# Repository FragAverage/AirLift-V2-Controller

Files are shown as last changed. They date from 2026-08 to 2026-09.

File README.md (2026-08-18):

# AirLift V2 Controller

The **AirLift V2 Controller** is a man-in-the-middle controller that sits inline
between an **AirLift V2 Controller controller** and the **air-management
manifold**. It **decodes the proprietary 9600-baud LIN-wired protocol**
in both directions, **rewrites frames if required** so a phone or the vehicle can
drive presets and manual air-up/down without ever desyncing the OEM Controller,
and **reads the vehicle CAN bus** for ignition sensing, lock/unlock triggers (like key fob)
and a live pressure broadcast. Everything is configured from a phone over
**Wi-Fi** — no laptop or serial cable needed in the car.

It runs on the same **ESP32 DevKit V1 (WROOM-32)** PCB as the
[MFSW Controller](https://forbes-automotive.com/products/lin-mfsw-controller),
under the Arduino framework, using both hardware UARTs for the two LIN sides and
the ESP32 **TWAI** peripheral for CAN.

> The firmware acts as a relay and only intercepts
> the manifold bus transiently while a command is queued — control always
> returns to the controller automatically.

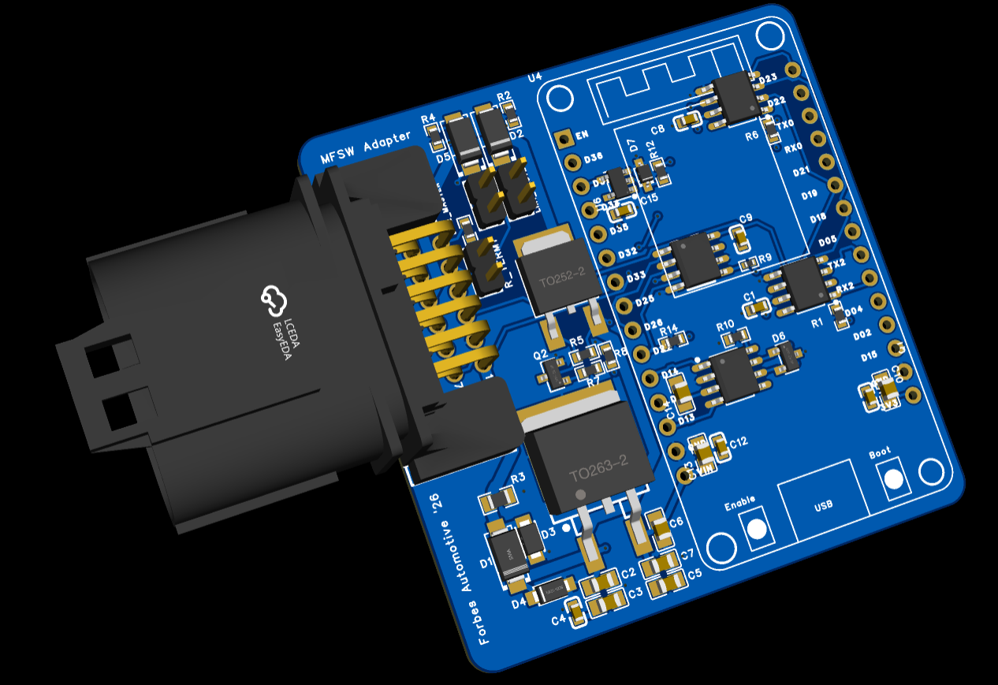
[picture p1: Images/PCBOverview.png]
PCB Overview


---

## Features at a Glance

| Feature | Detail |
|---|---|
| Dual-LIN | Dual LIN channels for Controller (UART1) and manifold (UART2) in dedicated FreeRTOS tasks |
| AirLift Decoder | Decodes every observed frame: FA/F3 polls & replies, the 17-byte status frame, and the 14-byte format-B pressure broadcast |
| Rewrite-in-flight injection | Presets, manual buttons, mode-switch — with verified checksums; the manifold only ever sees one continuous master, so it can't desync |
| Preset editor | Each of 8 presets stored as a `(frontPsi, rearPsi)` in EEPROM, plus a live **Learn** capture from the Controller to allow the user to learn each preset |
| Auto air-out | On ignition loss, broadcast the configured "air-down" target (preset or manual), hold, then turn off manifold power |
| CAN / TWAI | Powertrain quiet-bus ignition detection **or** Comfort-CAN lock/unlock triggers, plus a ~10 Hz pressure broadcast onto the selected bus |
| SavvyCAN GVRET | Capture/inject CAN over Wi-Fi (TCP 23) or USB serial for reverse-engineering |
| Lock/unlock air actions | A double fob-unlock airs the car up; a double fob-lock airs it down (both individually selectable) |
| High-side driver | Powers the controller whenever the vehicle is awake, with configurable CAN silence / min-FPS thresholds |
| Slave display | ~10 Hz ESP-NOW broadcast of pressures / preset / air state to a cluster-mounted CYD display (`SlaveDisplay/`) |
| Wi-Fi UI | Overview, Presets, Settings, Diagnostics, OTA |
| Power management | Auto Wi-Fi-off + CPU reduction 1 minute after the last client disconnects; a fresh CAN burst wakes it back up |
| OTA updates | Flash new firmware from the browser over Wi-Fi |
| EEPROM storage | All settings and presets stored to ESP32 Preferences |

---

### Purchase

The controller runs on the same PCB as the LIN MFSW Controller, available here:
[LIN MFSW Controller — Forbes Automotive](https://forbes-automotive.com/products/lin-mfsw-controller)

---

## Compatibility

Designed for the **AirLift V2** controller + manifold pair that communicate over a
**9600-baud 8N1 LIN-transceiver bus**. The controller is the **bus master** (the
bus is silent when it is unplugged). Frame formats, button codes and checksums
in [`include/defs.h`](include/defs.h) were reverse-engineered from live Saleae
captures (see [`Documents/`](Documents/)) — treat them as a known-good baseline
and re-verify against your own hardware before relying on any injected output.

CAN frame IDs (Comfort fob, broadcast) are **VW PQ-specific** and configurable.

---

## Hardware Overview

### External Interfaces

| Function | Part / circuit |
| --- | --- |
| Controller LIN (LIN 1) | LIN transceiver on `Serial1`, 9600 8N1 — the controller is the master, this device relays it |
| Manifold LIN (LIN 2) | LIN transceiver on `Serial2`, 9600 8N1 — the manifold is the slave |
| CAN | ESP32 TWAI + transceiver (TJA1050 / SN65HVD230); 500 kbit/s Powertrain or 100 kbit/s Comfort |
| Ignition sense (aux) | Optional 12 V level input on the shared aux pin (GPIO 39, input-only) for instant ignition |
| High-side driver | Transistor output (OUTPUT1) supplies +12 V to the controller during ignition-off air-out (5A max.) |

### Pin Map

Defined in [`include/defs.h`](include/defs.h):

| Group | Signal | GPIO |
| --- | --- | --- |
| LIN 1 (Controller) | TX / RX | 17 / 16 |
| LIN 2 (manifold) | TX / RX | 23 / 22 |
| LIN transceivers | Wake / CS-EN | 18 / 19 |
| CAN / TWAI | RX / TX | 13 / 14 |
| Ignition sense | Aux input (input-only pin) | 39 |
| High-side driver | Controller +12 V ("PNP") | 21 |

UARTs are 9600 8N1; CAN is 500 kbit/s (Powertrain) or 100 kbit/s (Comfort).

### Main Connector

The device breaks out to a single 12-way **MX23A12NF1** connector (shared PCB
with the MFSW controller):

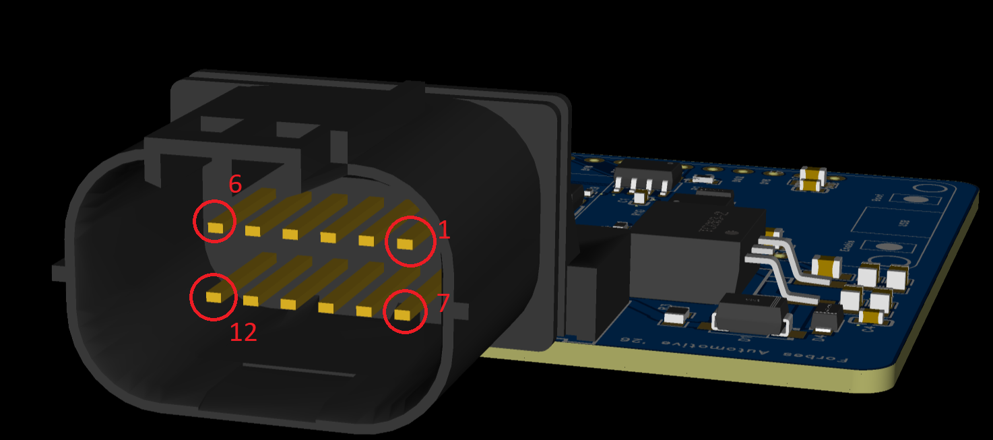
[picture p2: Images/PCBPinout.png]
Main Connector Pinout


> Viewed into the mating face: the top row runs pin **1** (right) to pin **6**
> (left), and the bottom row runs pin **7** (right) to pin **12** (left).

| Pin | Signal | AirLift use |
| --- | --- | --- |
| 1 | `PWR_IN` | 12 V switched / ignition supply |
| 2 | `GND` | Ground |
| 3 | `LIN1` | Controller LIN bus |
| 4 | `LIN2` | Manifold LIN bus |
| 5 | `CHASSIS_CANH` | CAN high |
| 6 | `CHASSIS_CANL` | CAN low |
| 7 | `ANALOG_LIGHT_IN` | Optional ignition-sense input (aux) |
| 8 | `RA` | Unused (resistive output not populated) |
| 9 | `5V` | 5 V rail — typically not required |
| 10 | `OUTPUT1` | Controller +12 V high-side driver |
| 11 | — | Unused |
| 12 | — | Unused |

---

## Jumpers

The shared PCB carries three configuration jumpers:

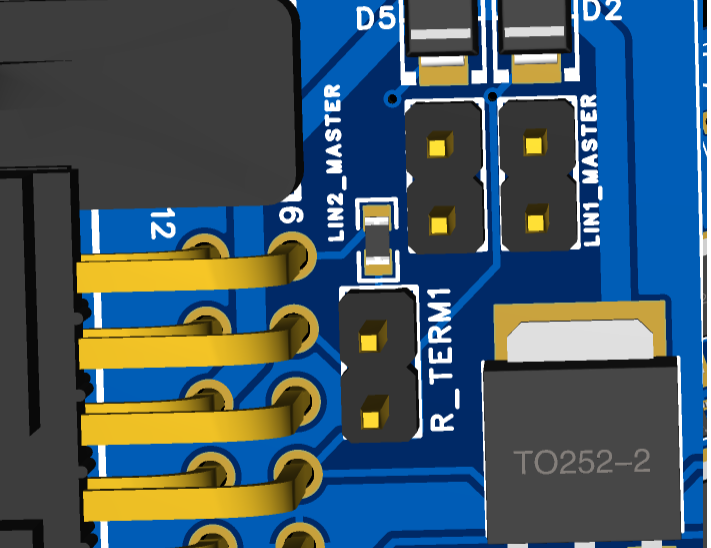
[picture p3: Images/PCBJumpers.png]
Board Jumpers


### LIN1_MASTER

Master pull-up on **LIN 1** (the controller bus). The AirLift Controller provides
the bus master, so this jumper is normally **left off** on the adapter — fit it
only if bench-testing without the real Controller attached.

### LIN2_MASTER

Master pull-up on **LIN 2** (the manifold bus). Fit it if the adapter must
provide the master pull-up on the manifold side; remove it if the manifold
harness already supplies one.

### R_TERM1

The **CAN bus termination resistor**. If this is the only device on the CAN
network leave it fitted; if the vehicle bus is already terminated, remove it.

---

## How It Works

The two LIN sides and the CAN bus each run in dedicated FreeRTOS tasks. The
firmware never seizes the manifold bus outright — the real Controller keeps
polling at its own rate and the firmware simply **rewrites those
frames as they pass through**. Because the manifold only ever sees one
continuous, correctly framed master it can never desync.

```
Controller LIN (master)                Manifold LIN (slave)              Vehicle CAN
        │                                   ▲                              │
        ▼ ControllerToManifoldTask (core 1)   │ manifoldToControllerTask       ▼ ignitionTask (core 0)
 parse poll / button ────────────┐          │ (core 1)                pollCanRx()
        │                        │          │  parse status/pressure       │
   RESTING: byte relay ──────────┼──────────┘  RESTING: byte relay         ▼ switch(id):
        │                        │          ▲       │                 Comfort 0x291 → lock/unlock
   COMMAND: drop poll,           │          │       ▼                       │
   drive manifold ~20 Hz ────────┘   rewrite reply, credit-gated       air-up / air-down queue
        (transformControllerFrame)      relay back to Controller                │
                                                                            ▼ canBroadcastTick()
                                                                     8-byte pressure frame (~10 Hz)
```

### Resting vs. Command

- **Resting** (the default) is a real-time byte-for-byte relay in both
  directions. Both channels still parse a side-channel copy of the traffic, so
  pressures, mode and button state stay live without slowing the bus.
- **Command** (a queued web/CAN action) drops the Controller's messages and drives the manifold at the OEM's active ~20 Hz rate. 

### Air-up / Air-down Triggers

| Source | Action |
| --- | --- |
| Web UI preset / manual buttons | Queue a preset target or manual corner move |
| Ignition loss (`airOutOnIgnOff`) | Broadcast the configured air-down target, hold, drop Controller power |
| Comfort-CAN **double unlock** (`airUpOnFobDouble`) | Air up to the configured preset / PSI |
| Comfort-CAN **double lock** (`airDownOnFobDouble`) | Air down to the configured preset / PSI |

Manual-target moves are closed-loop: the firmware pulses the matching corner
button until the measured axle PSI reaches the target (within tolerance) or the
60s timeout expires.  This may need adjustment(!).

---

## LIN Protocol (Reverse-Engineered)

### Format A — FA-framed polls and replies

```
FA  <payload bytes>  F3
```

**Controller → Manifold (master polls)**

| Bytes | Meaning |
|---|---|
| `01 00 05` | idle poll |
| `01 41 XX YY` | MANUAL-mode button event, `YY = (0xC4 - XX) & 0xFF` |
| `01 14 40 00 00 00 B1` | PRESET-mode entry poll (state `0x40`, one-shot) |
| `01 14 43 00 00 00 AE` | PRESET-mode steady poll (state `0x43`) |
| `01 16 47 TL TR 0F TL TR CHK` | preset target broadcast; `TL`/`TR` = front/rear PSI × 2 |

**Manifold → Controller (slave replies)**

| Bytes | Meaning |
|---|---|
| `10 F1 00 05` | idle reply |
| `10 F1 04 01` | reply, MANUAL mode |
| `10 F1 01 04` | reply, PRESET mode |
| `10 0E 00 25 …` | 17-byte status frame (see below) |

### Manual Button Codes (`01 41 XX YY`, payload[2])

Upper nibble = axle (5 = front, 6 = rear); lower nibble = one-hot bit per
(side, direction): bit0 = L-UP, bit1 = L-DOWN, bit2 = R-UP, bit3 = R-DOWN.

| Code | Button |  | Code | Button |
|---|---|--|---|---|
| 0x51 | FL_UP |  | 0x61 | RL_UP |
| 0x52 | FL_DOWN |  | 0x62 | RL_DOWN |
| 0x54 | FR_UP |  | 0x64 | RR_UP |
| 0x58 | FR_DOWN |  | 0x68 | RR_DOWN |
| 0x00 | release/idle |  | 0x80 | MODE_SWITCH (press+hold 1+5) |

Checksum: payload[3] = `(0xC4 - code) & 0xFF`.

### Format A — 17-byte status frame (Manifold → Controller)

```
FA 10 0E 00 MS  FL  RL  FR  RR  TANK  C8 00 00 00 33 00 CHK F3
```

- `payload[3]` = mode/compressor flags: bit5 (`0x20`) heartbeat, bit4 (`0x10`)
  poll-parity, bits0+2 (`0x05`) both set if the compressor is running.
- `payload[5..8]` = FL, RL, FR, RR raw PSI (× 1, **not** × 2).
- `payload[9]`    = tank raw PSI.
- `payload[16]`   = sum-checksum: `(0xFA + Σpayload[0..15] + chk) mod 256 == 0`.

### Format B — 14-byte pressure broadcast (idle-terminated, no FA/F3)

```
00 0A E6 7E   C8 00 4A 00   FL  FR  RL  RR  b12 b13
```

Pressure bytes are PSI × 2. Frame is terminated by ≥4 ms of bus silence
(`kFrameIdleMs`). Kept as a secondary pressure source; format-A status is
preferred when available.

> **Pressure Refresh Rate.** In resting mode pressures are parsed on
> *every* frame the manifold emits, so the on-device values are always as fresh
> as the bus allows. The dashboard now polls `/api/status` at 4 Hz (250 ms).
> The underlying rate is set by how often the manifold chooses
> to broadcast

---

## CAN / TWAI

- **Listen-only** by default; reset to NORMAL mode only when *CAN Broadcast* or
  SavvyCAN transmit is enabled, so the firmware never emits ACK/error bits onto
  a bus while just monitoring.
- Re-initialised in [`src/CAN.cpp`](src/CAN.cpp) (`canReinit()`) when the
  enable flag, ID or bus rate changes via `/api/settings`.

### CAN Source

Exactly one CAN bus is active at a time (a single TWAI controller can only run
at one bit-rate):

- **Powertrain CAN** (500 kbit/s, default) — quiet-bus / minimum-FPS ignition
  detection. Presence is decided by combined activity: silence longer than
  `canSilSec` (default 10 s) **and** frame rate below `canMinFps` (default 50) →
  ignition OFF.
- **Comfort CAN** (100 kbit/s) — parses lock/unlock. `pollCanRx()` feeds each
  frame to a simple `switch (frame.identifier)` case statement; the Comfort fob
  frame (`0x291`, byte 0 = `0x4B` unlock / `0x8B` lock) sets the lock state, and
  a **double** press within 5s queues the configured air-up (unlock) or
  air-down (lock) action.

### Lock/Unlock → Air-Up/Down 

```
Comfort frame 0x291 → canProcessFrame() switch → unlock/lock + double-press detect
                                              → comfortFobDoubleUnlock / …Lock flag
ignitionTask → sees flag → queueTarget(air-up | air-down) → manifold drive
```

### Pressure Broadcast (firmware → vehicle bus)

~10 Hz (`kCanBroadcastPeriodMs = 100`), user-configured 11-bit ID (default
`0x520`), DLC 8:

```
[0] FL PSI*2   [1] FR PSI*2   [2] RL PSI*2   [3] RR PSI*2   [4] Tank PSI*2
[5] flags: bit0 compOn | bit1 ignOn | bit2 intercept | bit3 passthru
          | bits4-5 mode (0=unknown,1=manual,2=preset)
[6] seq counter (free-running)   [7] reserved (0)
```

### Slave Display Broadcast (firmware → ESP-NOW)

A one-way ~10 Hz (`kEspNowPeriodMs = 100`) broadcast to `FF:FF:FF:FF:FF:FF` of
the 24-byte `AirLiftData` struct in `include/airlift_espnow.h` — the receiving
end is the cluster display in **`SlaveDisplay/`**. Broadcast means no pairing and
no knowledge of the display's MAC; nothing is ever received.

```
float fl, fr, rl, rr, tank   // PSI
uint8 preset                 // 1-8 active preset, 0 = none
uint8 status                 // 0 idle, 1 raising, 2 lowering, 3 no signal
```

The struct must stay **byte-identical** to `SlaveDisplay/include/airlift_espnow.h`
(a `static_assert` on both sides guards the size; the receiver can only check the
length, not the field layout).

Two things the LIN wire does not carry directly, so the firmware derives them:

- **Active preset** — the wire has no preset index, only the target pressures
  from `01 16 47`. Those are matched back against the configured/learned preset
  table, which is the same mapping the UI's preset list uses. No match, or not in
  PRESET mode, sends `0` and the display shows `---`.
- **Raising / lowering** — the compressor bit only says the pump is running
  (also true while it refills the tank). Direction comes from a button being held
  right now (ours or the handheld's), and otherwise from the trend of the corner
  pressures, which also covers preset moves where the manifold closed-loops with
  no button held at all.

Because ESP-NOW rides the Wi-Fi radio, the soft-AP channel is pinned to
`kEspNowChannel` (1) to match the display's fixed `ESPNOW_WIFI_CHANNEL`, and the
radio is held up while the broadcast is enabled **and** the ignition is on — see
Power Management below. Toggle in **Settings → Slave Display (ESP-NOW)**.

### SavvyCAN

Enable one setting in **Settings → SavvyCAN**:

- **Wi-Fi GVRET**: connect SavvyCAN to `192.168.1.1:23` as a GVRET network device.
- **Serial GVRET**: connect SavvyCAN to the USB serial port at `1,000,000` baud.

All received frames are forwarded through a queue; SavvyCAN transmit
requests are sent to the vehicle bus while either transport is active.

---

## Power Management

The firmware bundles the universal `power_manager` module used across the
projects. Power state follows the **Wi-Fi client count**, and CAN traffic is the
**wake source** — matching the "sleep when idle, wake when you return to the car"
behaviour:

1. **Boot** — Wi-Fi AP is up and full power.
2. **Idle** — **1 minute after the last Wi-Fi client disconnects**, the module
   turns the WiFi off, drops the CPU 240 MHz → 80 MHz, and clears any web
   override so the controller rests as a pure pass-through. This happens even while the
   car is running (CAN active), keeping the linear regulator cool.
3. **Wake** — while reduced, the TWAI controller keeps receiving (we never
   light-sleep, so no wake interrupt is needed — `ignitionTask` drains the RX
   FIFO every 100 ms). When the bus goes from **quiet → active** and a genuine
   **burst of ≥ `kCanWakeFrameMin` (8) frames** arrives, the board wakes and
   rebuilds the AP for the idle window. It sleeps again 1 minute later if no
   client connected.

> With the ESP-NOW slave display enabled, the radio is **held up while the
> ignition is on** — a cluster gauge that goes blank a minute into a drive is
> worse than the regulator heat it saves. Ignition off (car parked, display
> unpowered) reduces exactly as described above. Turn the broadcast off in
> Settings to restore the old behaviour in full.

> Lock/unlock parsing and air-up/down run in `ignitionTask` and are **independent
> of Wi-Fi** — a fob double-unlock airs the car up whether or not the WiFi is
> awake. The wake-on-burst only restores the web UI.

| Action | Saving |
| --- | --- |
| Wi-Fi off | ~80–120 mA average (single biggest) |
| CPU 240 MHz → 80 MHz | Moderate reduction in active current |
| Bluetooth controller released at boot | ~60 KB RAM freed; small idle saving |
| Onboard LED off at boot | Tiny but persistent saving |

A single stray CAN frame will **not** wake the AP, and a continuous stream that
started while awake will **not** re-wake it after it sleeps — only a fresh
quiet-to-active burst does. An ignition power-cycle always brings Wi-Fi back.

---

## Wi-Fi & Web Interface

Connect to the **`AirLift-V2 Controller`** Wi-Fi access point and browse to
**`http://192.168.1.1/`**. All changed settings are saved automatically.

| Tab | Purpose |
| --- | --- |
| **Overview** | Live FL/FR/RL/RR/Tank PSI, compressor LED, mode, press-and-hold corner buttons (Pointer Events with a safety release), and bus health |
| **Presets** | 8 named buttons + inline `(frontPsi, rearPsi)` editor |
| **Settings** | Pass-through, intercept, air-out-on-ignition-off, air-up/down on fob double-press, CAN source + silence/min-FPS, CAN broadcast ID, SavvyCAN |
| **Diagnostics** | High-side driver override, bus counters, CAN broadcast sent/errors |
| **OTA** | Upload a firmware `.bin` over Wi-Fi and reboot |

### Learn Mode

Enable a preset slot in the UI, then press the matching physical preset on the
Controller: the next `01 16 47 …` target broadcast on the wire is captured into
that slot (the wire carries no preset index, so the slot is bound to the button
you press). Learn windows time-out after a few seconds.

---

### Frame Builders

| Function | Output |
|---|---|
| `buildIdlePoll(out)` | `FA 01 00 05 F3` |
| `buildManualButtonPoll(code, out)` | `FA 01 41 XX (0xC4-XX) F3` |
| `buildPresetTargetPoll(frontPsi, rearPsi, out)` | `FA 01 16 47 TL TR 0F TL TR CHK F3` |
| `buildEnterManualPoll(out)` / `buildEnterPresetPoll(out)` | mode-switch / preset-entry polls |

---

## Configuration

### Feature Flags

Serial debug is defined at the top of [`include/defs.h`](include/defs.h). Set `enableDebug 0` to turn off
everything in one place.  With it on, flip individual categories to focus on a
subsystem. Each category is ANDed with `enableDebug`, and every line is
auto-tagged (e.g. `[CAN]`, `[WiFi]`).

| Flag | Tag | Covers |
| --- | --- | --- |
| `enableDebug` | — | **Master** — `0` disables all serial debug |
| `debugSys` | `[SYS]` | Boot + 1 Hz telemetry |
| `debugPower` | `[PWR]` | Reduced-power / wake (power_manager) |
| `debugWifi` | `[WiFi]` | Soft-AP bring-up |
| `debugIO` | `[IO]` | High-side / controller power / UART init |
| `debugCAN` | `[CAN]` | TWAI driver, vehicle CAN, fob, wake-burst |
| `debugLIN` | `[LIN]` | AirLift LIN MITM (wire / mode / buttons) |
| `debugAPI` | `[API]` | REST / settings / OTA |
| `debugSavvy` | `[SAVVY]` | SavvyCAN GVRET control |

> Serial runs at `serialDebugBaud` (115200). Note: enabling **SavvyCAN Serial
> GVRET** takes over the USB UART at 1 Mbaud, so serial debug and serial GVRET
> are mutually exclusive.

### Key Defaults

| Setting | Default |
| --- | --- |
| LIN Baud | 9600 8N1 |
| CAN Source | Powertrain (500 kbit/s) |
| CAN Silence / min-FPS | 10 s / 50 fps |
| CAN Broadcast ID | `0x520` (disabled by default) |
| Comfort Fob ID / Unlock / Lock | `0x291` / `0x4B` / `0x8B` |
| Fob Double-press Window | 5 s |
| Wi-Fi Idle Timeout | 60 s (after last client) |
| CAN Wake-burst Minimum | 8 frames |
| Wi-Fi AP / IP | `AirLift-V2 Controller` / `192.168.1.1` |
| Pass-through Mode | ON (safe boot default) |

Settings persist to ESP32 Preferences (EEPROM)

---

## Version History

```
V1.00 — ESP32 rewrite: dual-UART rewrite-in-flight MITM, Wi-Fi UI, preset editor.
V2.01 — CAN/TWAI bridge (Powertrain/Comfort), pressure broadcast, SavvyCAN GVRET.
V2.10 — power management (Wi-Fi-client idle + CAN wake-on-burst),
        deferred WiFi bring-up on wake, high-side auto-release, fob boot-delay,
        command-mode idle masking, and single-master gated serial debug.
V2.11 — ESP-NOW broadcast to the slave cluster display, AP channel pinned,
        radio held up while the ignition is on.
```

---

## Disclaimer

Forbes Automotive accepts no responsibility for any incidents arising from the
use of this adapter. Frame IDs, button codes and calibration are vehicle- and
hardware-specific — verify against your own setup before relying on any injected
output or automatic air action.

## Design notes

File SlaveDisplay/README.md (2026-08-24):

# AirLift V2 — Slave Display

Gauge-cluster dashboard for the AirLift V2 MITM controller, with an
MFL-button-driven on-screen menu (see "MFL menu" below). Five boards (seven
PlatformIO envs — `round21` and `lcd147` each have an LVGL alternate build)
share this firmware:

- **`cyd`** (default) — **ESP32-2432S028R** ("Cheap Yellow Display"): 2.8"
  ILI9341 320×240 + XPT2046 resistive touch. TFT_eSPI.
- **`round128`** — **Waveshare ESP32-S3-Touch-LCD-1.28**: 1.28" GC9A01
  240×240 round panel + CST816T capacitive touch. TFT_eSPI.
- **`round21`** — **Waveshare ESP32-S3-Touch-LCD-2.1**: 2.1" ST7701 480×480
  round panel driven over the ESP32-S3's RGB-parallel LCD peripheral (not
  SPI) + CST820 capacitive touch, both gated through a TCA9554 I2C IO
  expander. Arduino_GFX — see "The round21 board" below for why.
- **`round21_lvgl`** — the same physical `round21` board/panel, rendered
  with LVGL widgets instead of Arduino_GFX draw calls. Same on-screen layout
  as `round21` on purpose; an alternate build, not a fallback — see "The
  round21 board" below.
- **`oled13`** — generic ESP32-S3 devkit + 1.3" SH1106 128×64 monochrome
  OLED, I2C. The intended **production screen size** — no touch hardware at
  all, every input is the MFL menu. Adafruit_SH110X — see "The oled13 board"
  below.
- **`lcd147`** — **Waveshare ESP32-S3-LCD-1.47B**: 172×320 ST7789 SPI panel,
  rotated to a 320×172 landscape canvas, no touch hardware. TFT_eSPI, shares
  `display.cpp`/`touch.cpp` with `cyd`/`round128`.
- **`lcd147_lvgl`** — the same physical `lcd147` board/panel, rendered with
  LVGL widgets instead of raw TFT_eSPI draw calls. Unlike `round21_lvgl`,
  TFT_eSPI stays in the picture (this panel's ST7789 is already well
  supported by it) — see "`lcd147_lvgl`: the same board, rendered with
  LVGL" below.

The master broadcasts `AirLiftData` (pressures/preset/status) and
`AirLiftButtons` (live MFL button state) over ESP-NOW; the unit renders them
and holds no state beyond the last packet of each. It also broadcasts back —
`AirLiftCommand`, only when the on-screen menu confirms an action — but
still needs no pairing and no knowledge of the master's MAC either
direction, same broadcast model throughout.

`display.cpp`/`touch.cpp` are identical between `cyd` and `round128` — every
pixel position, font size, and pin comes from `include/config.h`, gated on
the `DISPLAY_ROUND` build flag. `round128`'s grid is the same 2x2-corner /
tank-preset-strip / status-bar layout as the CYD, just scaled down and inset
so every box sits inside the circle the physical bezel actually shows — see
"Round panel geometry" below before touching the numbers.

`round21` can't share those files (TFT_eSPI has no working driver for its
ST7701 RGB-parallel panel — see "The round21 board" below), so it gets its
own `display_round21.cpp`/`touch_round21.cpp`/`tca9554.cpp`, selected per env
by `build_src_filter` in `platformio.ini`. It follows the *same* 2x2-grid /
strip / status-bar layout and the same `display::`/`touch::` interface as the
other two, just against a different rendering backend — `main.cpp` and the
ESP-NOW receive layer (`espnow_link.cpp`) don't know or care which board
they're running on.

`round21_lvgl` is a second display backend for that same board/panel,
`display_round21_lvgl.cpp`, built from LVGL widgets instead of Arduino_GFX
draw calls — same `display::` interface, same 2x2-grid/strip/status-bar
layout, `main.cpp` no more aware of it than of any other board. It shares
`panel_round21.cpp` (the ST7701/RGB-peripheral bring-up) and
`touch_round21.cpp` verbatim with `env:round21` — only the rendering backend
and `lib_deps` differ. See "The round21 board" below.

`lcd147`, unlike `round21`, *can* share `display.cpp`/`touch.cpp` with
`cyd`/`round128` — its ST7789 panel is a normal TFT_eSPI-supported SPI part,
just rotated to a 320×172 landscape canvas (`BOARD_LCD147` in `config.h`).
`lcd147_lvgl` is its LVGL alternate build (`display_lcd147_lvgl.cpp`), same
relationship to `lcd147` as `round21_lvgl` has to `round21` — but since
TFT_eSPI already works fine for this panel, LVGL sits on top of it rather
than replacing it: TFT_eSPI still does panel bring-up, LVGL's flush callback
just calls `tft.pushImage()`. `touch.cpp` is shared unchanged by both.

```
  0                160               319
  +--------------------+--------------------+   0
  |  FL                |  FR                |
  |       62.5         |       61.8         |     ← Font 6, white
  +--------------------+--------------------+   84
  |  RL                |  RR                |
  |       78.0         |       77.4         |
  +--------------------+--------------------+  168
  |  TANK              |  PRESET            |
  |    145 PSI         |     DRIVE          |     ← cyan / yellow, Font 4
  +--------------------+--------------------+  218
  |               RAISING                   |     ← colour-coded status bar
  +-----------------------------------------+  240
```
*(`cyd` — 320×240 landscape, edge-to-edge)*

## Build & flash

```bash
pio run                       # build the default env (cyd)
pio run -e round128           # build the 1.28" round panel
pio run -e round21            # build the 2.1" round panel (Arduino_GFX)
pio run -e round21_lvgl       # build the 2.1" round panel (LVGL)
pio run -e oled13             # build the 1.3" OLED (production size)
pio run -e lcd147             # build the 1.47" landscape panel (TFT_eSPI)
pio run -e lcd147_lvgl        # build the 1.47" landscape panel (LVGL)
pio run -e round128 -t upload # flash over USB
pio device monitor -e round128 --baud 115200
```

All TFT_eSPI configuration is passed as `-D` build flags from `platformio.ini`
(`USER_SETUP_LOADED=1`), so the library folder is never edited and the config
survives a clean build or a `pio pkg update`. `User_Setup_CYD.h` in this folder
is the same configuration as a drop-in `User_Setup.h`, for Arduino IDE builds.

TFT_eSPI emits `#warning TOUCH_CS pin not defined` during the build, on the
two TFT_eSPI envs. That is expected and correct: neither board's touch
controller is driven by TFT_eSPI's built-in (resistive, SPI) touch support —
the CYD's XPT2046 sits on its own VSPI bus via `XPT2046_Touchscreen`, and
`round128`'s CST816T is a capacitive I2C part via `CST816S`, which TFT_eSPI
has no concept of at all. A `TOUCH_CS` would (on the CYD) make TFT_eSPI talk
to the touch chip over the display's own bus, which is not how the board is
wired. `round21` doesn't use TFT_eSPI at all, so this doesn't apply to it.

## Build flags worth knowing

| Flag | Default | Purpose |
| --- | --- | --- |
| `ESPNOW_WIFI_CHANNEL` | `1` | **Must match the master's channel.** |
| `ENABLE_TOUCH` | `0` | Compiles in the tap zones. Off because the unit is cluster-mounted. |
| `DEMO_MODE` | `0` | Animates fake pressures so the panel can be tested with no master present. |
| `DISPLAY_ROUND` | *(unset on `cyd`, `1` on `round128`)* | Selects `round128`'s pins/geometry/touch driver in `config.h`. Not something you set by hand — it's baked into that env's `build_flags`. |
| `BOARD_ROUND21` | *(unset elsewhere, `1` on `round21` and `round21_lvgl`)* | Selects the round21 board's pins/geometry/touch driver in `config.h` — same for both display backends, this is a rendering-backend swap, not a different board. Also baked into each env's `build_flags`. |
| `BOARD_LCD147` | *(unset elsewhere, `1` on `lcd147` and `lcd147_lvgl`)* | Selects the lcd147 board's landscape geometry in `config.h` — same for both display backends. Also baked into each env's `build_flags`. |

## Round panel (`round128`)

Waveshare ESP32-S3-Touch-LCD-1.28: ESP32-S3R2, 16MB flash, GC9A01 240×240
round panel on SPI, CST816T capacitive touch + QMI8658 IMU sharing one I2C
bus (SDA 6 / SCL 7 — IMU is present on the board but this firmware doesn't
use it). Flashes over the onboard CH343P USB-UART bridge, not the S3's native
USB, so it's a plain serial upload like the CYD.

Pin sourcing: the GC9A01 SPI pins come from three independent sources that
all agree — TFT_eSPI's own bundled
`User_Setups/Setup302_Waveshare_ESP32S3_GC9A01.h`, and two community
Waveshare pinout writeups. The CST816T touch pins (`TOUCH_SDA/SCL/RST/IRQ` in
`config.h`) come from a single community-verified PlatformIO project for this
exact board — lower confidence than the panel pins, since Waveshare sells a
plain (non-touch) `ESP32-S3-LCD-1.28` and a different `DualEye-1.28` board
with similar names and different wiring. **Verify against your unit's
schematic before relying on touch**, the same way this repo's other
hardware docs ask you to re-check MFL/LIN pin assignments against your own
car.

### Round panel geometry

The panel's framebuffer is a normal 240×240 rectangle — the round glass just
physically masks whatever gets drawn outside its visible circle. Rather than
give the round build its own layout code, its grid is the CYD's grid,
inset so every box's farthest corner stays a few px inside a conservative
118px-radius safe circle (measured from centre (120,120), not from any
physical test — a 240-diameter circle's true radius is 120, and a couple of
those px are typically lost to the bezel/lens, so this stays back from that
edge on purpose). The math is inline as a comment in `config.h` next to
`GRID_X0`/`GRID_Y0`: if your unit's visible circle is smaller and the grid's
corners get clipped by the bezel, shrink those two constants (and grow
`STATUS_H` to keep the bottom edge symmetric) until it clears.

Consequently the corner/strip fonts on `round128` are smaller than the CYD's
(Font 4, 26px, vs Font 6, 48px) — the round panel's cells are physically
smaller, so the CYD's big digits-only Font 6 no longer fits.

## The round21 board (`round21`)

Waveshare ESP32-S3-Touch-LCD-2.1: ESP32-S3-WROOM-1-N16R8 (16MB Quad flash,
8MB Octal PSRAM), ST7701 480×480 round panel, CST820 capacitive touch,
TCA9554 I2C IO expander. This is a materially different board from the other
two, not just a different pinout:

- The panel isn't SPI. It's driven over the ESP32-S3's dedicated RGB-parallel
  LCD peripheral (16 data lines + HSYNC/VSYNC/DE/PCLK) — the same peripheral
  used for the RGB parallel LCDs on things like the ESP32-S3-BOX. A short
  "3-wire SPI"-style link (CLK + MOSI only, no MISO, no real CS pin) is used
  *only* to send the ST7701's one-time gamma/voltage/timing register init;
  actual pixel data never touches that link.
- **TFT_eSPI has no working ST7701-RGB support** (this is an open, unresolved
  upstream issue, not something fixable from this repo), so this board can't
  reuse `display.cpp`/`touch.cpp` the way `round128` does. It uses
  [Arduino_GFX](https://github.com/moononournation/Arduino_GFX) ("GFX Library
  for Arduino") instead, via a thin custom `Arduino_GFX` subclass
  (`Arduino_ST7701` in `display_round21.cpp`) that routes the library's
  drawing calls to `esp_lcd_panel_draw_bitmap()` against the panel's
  PSRAM framebuffer.
- The panel's reset and init-SPI "CS" aren't real GPIOs — they're bits on a
  **TCA9554** I2C GPIO expander (`tca9554.cpp`), which also gates the CST820
  touch controller's reset and the panel's power-enable line.

**Pin/init sourcing and confidence:** the RGB data-pin mapping, TCA9554
usage, and the full ST7701 register-init sequence (gamma curves, VOP/VCOM/
VGH/VGL, timing) are ported **byte-for-byte** from a community-posted copy of
what is, by its file names (`Display_ST7701.cpp`, `TCA9554PWR.cpp`,
`Touch_CST820.cpp`, `I2C_Driver.cpp`), Waveshare's own Arduino demo for this
board. Do not hand-edit the register values in `st7701Init()` — they're
panel-specific gamma/voltage/timing, not arbitrary numbers, and this hasn't
been tested against real glass. One deliberate deviation from that source:
the demo also constructs an `Arduino_ESP32RGBPanel` bus object and calls its
`begin()`, but nothing in its actual drawing path uses it (only the directly-
created `esp_lcd_panel_handle_t` does) — reproducing that would mean
configuring the RGB peripheral through two separate, uncoordinated paths, so
it's dropped here as vestigial.

**PSRAM matters on this board** in a way it doesn't on the other two: the RGB
panel's two framebuffers live in PSRAM (`fb_in_psram = true`, `double_fb =
true` in `rgbPanelInit()`), so `platformio.ini`'s `qio_opi` memory-type
config (Quad flash + Octal PSRAM, matching the N16R8 module) has to be
correct or the panel simply won't come up. If your unit uses a different
ESP32-S3 module variant, check its flash/PSRAM mode before flashing.

**round21 layout** follows the same inscribed-square reasoning as
`round128`'s (see above) — this panel is 4x the pixel area with a much more
generous safe circle, so the numbers in `config.h`'s `BOARD_ROUND21` block
have more headroom, but they're equally unverified against real glass.
Arduino_GFX's built-in font is a fixed 6x8px bitmap glyph scaled by an
integer `setTextSize()` — there's no font-ID system like TFT_eSPI's, hence
the `VALUE_TEXTSIZE_CORNER`/`LABEL_TEXTSIZE`/etc. macros instead of
`VALUE_FONT_CORNER`.

Unlike the two TFT_eSPI boards, `round21`'s value redraws skip the
sprite-composition trick entirely (`drawValue()` just does a plain
`fillRect` + centred `print()`). That trick exists on the other boards to
hide the visible time an SPI transfer takes; here the "display" is a PSRAM
framebuffer the RGB peripheral scans out continuously in hardware, so writing
into it is just a RAM store with no transfer-time flicker to hide. The
diffed-redraw cache (skip repainting a box whose text didn't change) is kept
anyway, purely to save CPU at the ~10 Hz update rate.

### `round21_lvgl`: the same board, rendered with LVGL

Same physical board/panel as `round21` above, same on-screen layout, same
`display::` interface — only the rendering backend differs
(`display_round21_lvgl.cpp`, `lvgl/lvgl @ ^9.5.0` instead of Arduino_GFX).
An alternate build meant to be compared against the known-working `round21`
env, not a replacement for it — both stay buildable.

`panel_round21.cpp`/`.h` holds the ST7701/RGB-peripheral bring-up (TCA9554
power/reset sequencing, the byte-for-byte-ported init registers,
`rgbPanelInit()`, backlight PWM) that both `display_round21.cpp` and
`display_round21_lvgl.cpp` call into — split out specifically so that
unverified-on-glass panel bring-up exists exactly once rather than being
duplicated across backends. `touch_round21.cpp` and `tca9554.cpp` are reused
completely unchanged by `round21_lvgl` too.

LVGL's flush callback draws straight into the panel via
`esp_lcd_panel_draw_bitmap()` against `panel_round21::handle()` — the same
ESP-IDF call the Arduino_GFX backend uses, just handed a whole flushed
rect at once (LVGL's own `LV_DISPLAY_RENDER_MODE_PARTIAL` draw buffers,
plain heap `malloc`, not PSRAM) instead of per-pixel/per-line calls.
`main.cpp` has no idea LVGL exists — `update()`/`drawMenu()` each start by
calling a small `pumpLvgl()` helper (`lv_tick_inc()` + `lv_timer_handler()`)
so LVGL's own timing actually advances on `main.cpp`'s ~10ms loop cadence.

Config lives in `include/lv_conf.h`, picked up via the `round21_lvgl` env's
`-D LV_CONF_INCLUDE_SIMPLE=1` build flag — same "config via build flags,
library folder never edited" convention as this project's TFT_eSPI
`USER_SETUP_LOADED` flags. That env also needs an explicit `-I include` build
flag: `LV_CONF_INCLUDE_SIMPLE`'s `#include "lv_conf.h"` is a quote-include,
and PlatformIO does not put this project's `include/` directory on a
*library's own* source files' include path (only its `-D` build flags reach
them, confirmed via `pio run -v`) — without `-I include`, LVGL's `.c` files
silently fall back to their own defaults instead of this project's `lv_conf.h`.

One deliberate visual deviation from `round21`: the MFL menu's
`MANUAL_ACTIVE` direction indicator is LVGL's bundled `LV_SYMBOL_UP`/
`LV_SYMBOL_DOWN`/`LV_SYMBOL_MINUS` glyphs instead of a hand-drawn filled
triangle — LVGL has no filled-polygon primitive as cheap as a symbol glyph.
Untested on real hardware, same caveat as the panel bring-up above.

## The oled13 board (`oled13`)

Generic ESP32-S3 devkit + 1.3" SH1106 128×64 monochrome OLED, I2C — the
**intended production screen size**, unlike the other three boards which are
all off-the-shelf dev-board bring-up rigs. No touch hardware exists on this
board at all (`touch_oled13.cpp` is an unconditional stub); every input is
the MFL menu instead.

Wiring is whatever you actually used — this is a bare devkit + a separate
OLED breakout, not a fixed-pinout product like the other three boards, so
`config.h`'s `I2C_SDA_PIN`/`I2C_SCL_PIN`/`OLED_I2C_ADDR` under `BOARD_OLED13`
need to match your build. `display_oled13.cpp`'s `begin()` tries both common
addresses (0x3C, 0x3D) and, if neither ACKs, scans the whole I2C bus and logs
what it finds — check the serial log first if the screen stays blank.

**Layout is a genuine redesign, not a shrunk version of the other boards'
2x2 grid** — 128×64 monochrome is a different enough form factor (no colour,
a fraction of the pixel budget) that it gets its own compact layout:

- Corner pressures are the primary readout, big (`GAUGE_TEXTSIZE` 2, 16px),
  arranged as two rows — "F" (front: FL left, FR right) and "R" (rear: RL
  left, RR right) — with a narrow single-letter axle label instead of a
  `FL:`/`FR:` prefix, which wouldn't fit at this size. Same left/right =
  driver/passenger-side convention the other boards' 2x2 grid uses.
- Status has no room for its own text row here, so it's a single glyph in
  the top-right corner instead — `^`/`v` for raising/lowering, `X` for no
  signal, nothing drawn for idle (a blank icon reads as "no data" more than
  "nothing wrong"). See `STATUS_CHAR_*` in `config.h`.
- Tank and preset get their own small rows lower on the screen, freed up by
  moving status out of a full row.
- The MFL menu's 8-item Presets list can't fit in one screen at this
  resolution (title + 3 rows is already the full 64px height), so
  `drawMenu()` scrolls a `MENU_VISIBLE_ROWS`-tall window that keeps the
  cursor centred, with a "N/total" hint in the title row — see `config.h`'s
  `MENU_VISIBLE_ROWS` comment.

No PSRAM needed (the whole SH1106 framebuffer is 128×64/8 = 1KB), so unlike
`round21` this env doesn't touch `qio_opi`/PSRAM config at all — just the
same native-USB `ARDUINO_USB_CDC_ON_BOOT` requirement `round21` has (see that
section above).

## The lcd147 board (`lcd147`)

Waveshare ESP32-S3-LCD-1.47B: ST7789 172×320 SPI panel (write-only, no MISO
wired — same as `round128`'s GC9A01), rotated to a 320×172 landscape canvas
(`TFT_ROTATION` in `config.h`'s `BOARD_LCD147` block), no touch hardware.
Also has an onboard QMI8658 six-axis IMU, TF/SD slot, and an addressable RGB
LED, none of which this firmware uses (the LED is explicitly written off at
boot — see `display::begin()` — since it otherwise powers up showing an
undefined colour).

Unlike `round21`, this panel's ST7789 already has full working TFT_eSPI
support, so `lcd147` shares `display.cpp`/`touch.cpp` with `cyd`/`round128`
same as `round128` does — no board-specific display/touch files needed.

One real hardware quirk: **the backlight is not software-controlled on this
board.** GPIO46 (this board's `TFT_BL` pin per Waveshare's own pin table) is
the one genuinely input-only GPIO on the ESP32-S3 — it cannot drive PWM or
any digital output at all, confirmed at runtime (`ledcAttach`/`digitalWrite`
both error `"IO 46 is not set as GPIO"` despite the panel itself working
fine). The backlight is evidently hard-wired always-on, so `setBacklight()`
is a no-op on this board specifically (`#ifdef BOARD_LCD147` in
`display.cpp`) — every other board's PWM fade-up in `splash()` simply has no
visible effect here.

### `lcd147_lvgl`: the same board, rendered with LVGL

Same physical board/panel as `lcd147` above, same on-screen layout, same
`display::` interface — only the rendering backend differs
(`display_lcd147_lvgl.cpp`, adding `lvgl/lvgl @ ^9.5.0` to `lib_deps`
alongside TFT_eSPI, not instead of it). An alternate build meant to be
compared against the known-working `lcd147` env, not a replacement for it —
both stay buildable. See "The round21 board" above for the general
LVGL-backend approach (draw buffers, `pumpLvgl()`, the DSEG7 retro digit
font) this env follows too — the one thing genuinely different here:

**TFT_eSPI stays in the picture**, unlike `round21_lvgl`. `round21_lvgl`
talks to the panel directly via `esp_lcd_panel_draw_bitmap()` because
TFT_eSPI has *no* working ST7701-RGB driver at all; that's not true here —
this panel's ST7789 is a completely ordinary TFT_eSPI-supported SPI part, so
bypassing it would just be reinventing well-tested panel bring-up for no
reason. LVGL's flush callback is a single `tft.pushImage()` call per
flushed rect — the standard, common LVGL+TFT_eSPI integration pattern.
`touch.cpp` is reused unchanged (this board has no touch hardware either
way, same as `lcd147`).

`config.h`'s `BOARD_LCD147` block also carries this backend's font-size
macros (`VALUE_FONT_PX_CORNER`/`VALUE_FONT_PX_STRIP`/etc.), sized for this
board's much shorter cells than round21's (`CELL_VALUE_H`=28,
`STRIP_VALUE_H`=22 here vs. 56/44 there) — the corner/manual-adjust DSEG7
digit font is 22px here (`font_dseg7_22`) and the tank digit font 16px
(`font_dseg7_16`), both in `lib/dseg7_font/` alongside round21_lvgl's 48px/
28px ones. Untested on real hardware (no `lcd147` unit was available to
flash when this was built) — same caveat as everything else in this repo
flagged "unverified against real glass."

## Wi-Fi channel

Applies to every board. ESP-NOW only works between radios parked on the
same channel, and this end never associates with anything, so the channel is
pinned explicitly at boot. If the
master is running its SoftAP (web UI) on a channel other than 1, set
`ESPNOW_WIFI_CHANNEL` to match or **no packets will ever arrive** — the display
will sit on `NO SIGNAL` with no other symptom.

## Master-side sender

Implemented in `PlatformIO/src/espnow_tx.cpp` (firmware v2.11+), enabled by
default and switchable in the master's web UI under **Settings → Slave Display
(ESP-NOW)**. It broadcasts at ~10 Hz from the soft-AP interface.

The struct in `include/airlift_espnow.h` must stay byte-identical on both ends
(24 bytes with default packing — there is a `static_assert` guarding it). The
master keeps its own copy at `PlatformIO/include/airlift_espnow.h`; **change one
and you must change the other.**

Broadcast means the display needs no knowledge of the master's MAC. The receiver
sanity-checks the length and drops anything that is not exactly `sizeof(AirLiftData)`.

Two fields are derived master-side rather than read off the LIN wire:

- **`preset`** — the wire carries no preset index, only the target pressures from
  the `01 16 47` broadcast. The master matches those against its configured /
  learned preset table. No match (or not in PRESET mode) sends `0`, which renders
  as `---`.
- **`status`** — `RAISING` / `LOWERING` come from a button being held right now
  or, failing that, from the trend of the corner pressures (which is what covers
  a preset move, where the manifold closed-loops with no button held). The
  compressor bit alone is not direction: it is also set while the tank refills.
  `NO_SIGNAL` is sent when the master itself has lost the manifold, so the
  display distinguishes "master gone" (its own 3 s link timeout) from
  "master fine, car's LIN bus is dead".

The master pins its soft-AP to channel 1 (`kEspNowChannel`) to match this end's
`ESPNOW_WIFI_CHANNEL`, and holds its radio up while the ignition is on so the
display does not go blank when its power-saving would otherwise drop Wi-Fi.

## MFL menu

The steering wheel's MFL cruise-control buttons are wired into the **master**
(GPIO34, opto-isolated — see `MFL-FINDINGS.md`), not this display. To let
those buttons drive an on-screen menu here, ESP-NOW is bidirectional between
the two ends for the first time:

- **Master → slave**, `AirLiftButtons` (`airlift_espnow.h`): live button
  *state* (not press/release events), broadcast at ~20 Hz — faster than the
  10 Hz `AirLiftData` telemetry, so menu navigation feels responsive.
  State rather than events matters here: ESP-NOW broadcast has no delivery
  guarantee, so a lost state frame just gets caught up by the next one,
  where a lost discrete "button pressed" event would be a permanently
  missed input. `menu.cpp` does its own rising-edge detection by diffing
  each new frame against the last one it saw.
- **Slave → master**, `AirLiftCommand`: sent once, when the menu confirms an
  action (currently only `CMD_SELECT_PRESET`). Same broadcast/unencrypted/
  no-pairing trust model as everything else this firmware sends or
  receives — the master can only be told to select from its own
  pre-configured preset table, never handed an arbitrary pressure target.

**Mapping** (`menu.cpp`): `IO` = enter the menu / select the highlighted
item, `PLUS`/`MINUS` = move the cursor up/down, `SET`/`ON` = back one level
(and back out of the top level returns to the gauge view). Two top-level
screens: **Presets** (select one — sends `CMD_SELECT_PRESET` and returns to
the gauge) and **Settings** (currently just backlight, adjusted live via
`display::setBacklight()`; not persisted — resets to `BACKLIGHT_PCT` on
reboot).

The menu is rendered by the same per-board `display::drawMenu()` each env
already has for the gauge (`display.cpp` for `cyd`/`round128`,
`display_round21.cpp` for `round21`) — board-agnostic `menu.cpp` only ever
deals in a `menu::View` (title + item list + cursor), never a pixel. Redraws
are whole-screen rather than diffed per element (unlike the gauge's
`update()`): the menu only changes on a button press, not a 10 Hz stream, so
there's no meaningful SPI/redraw cost to save by diffing it.

## Behaviour

- **Redraw is diffed, not cleared.** `drawStaticLayout()` paints the dividers and
  captions once in `setup()`; `update()` compares the *rendered text* of each
  value against what is on screen and `fillRect`s only the boxes that actually
  changed. Jittery floats that all format to the same string cost zero SPI traffic.
- **Pressures are whole psi.** Sub-psi resolution is noise on an air suspension
  gauge and churns the last digit on every packet, which reads as a flickering
  display. A value that can't be trusted (NaN, negative) renders as `---`.
- **Link loss.** No packet for 3 s → the status bar goes red `NO SIGNAL` and the
  held pressures are dimmed to dark grey, so a stale reading can't be mistaken
  for a live one.

## Touch (`ENABLE_TOUCH=1`)

Applies to `cyd`/`round128`/`round21`/`round21_lvgl` only — `oled13` and
`lcd147`/`lcd147_lvgl` have no touch hardware at all (`touch_oled13.cpp` and,
on those two lcd147 envs, `touch.cpp`'s `#if ENABLE_TOUCH` stub branch, are
unconditional no-ops), and every input on those boards is the MFL menu
instead. Tap-zone logic is the same shape on the other three boards
(`dispatch()`, in whichever `touch*.cpp` the env compiles): the
four corner quadrants, and preset down / preset up on the left / right of
the tank-preset strip, driven by that env's `GRID_X0/Y0`/`CELL_W`/`CELL_H`
geometry. Each hit currently just does a `Serial.printf` — the actual
command injection is master-side work still to be wired up. Their raw-read
front ends differ:

- **`cyd`** — XPT2046 resistive, its own SPI bus. Calibrated for raw X/Y
  200–3900, remapped to landscape with the axes swapped and Y mirrored in
  `mapRaw()`. If taps land in the mirrored position, swap the endpoints of one
  `map()` call there.
- **`round128`** — CST816T capacitive, I2C (`fbiego/CST816S`). Reports
  `touch.data.x/y` directly in panel space at rotation 0 — no raw-range
  calibration or axis remap needed. If your mounting uses a different
  `TFT_ROTATION`, the touch coordinates will need the same remap treatment
  `mapRaw()` gives the CYD.
- **`round21`** — CST820 capacitive, I2C, reset via the TCA9554 expander
  (`touch_round21.cpp`, register map ported from Waveshare's demo — see "The
  round21 board" above). Also reports coordinates directly in panel space at
  rotation 0, same caveat as `round128` if you change `DISPLAY_ROTATION`.

## Layout

| File | Contents |
| --- | --- |
| `include/config.h` | Per-board pins + layout geometry (`DISPLAY_ROUND`/`BOARD_ROUND21`/`BOARD_OLED13`/`BOARD_LCD147`-gated), colours, timeouts |
| `include/airlift_espnow.h` | The shared wire structs (`AirLiftData`, `AirLiftButtons`, `AirLiftCommand`) — **keep in sync with the master** |
| `src/espnow_link.cpp` | STA mode, fixed channel, receive callback (`AirLiftData` + `AirLiftButtons`), `sendCommand()` — shared, board-agnostic |
| `include/menu.h` / `src/menu.cpp` | MFL-button-driven menu state machine (edge detection, screens, cursor) — shared, board-agnostic, rendering-agnostic |
| `src/display.cpp` | `cyd`/`round128`/`lcd147` (TFT_eSPI): static layout + diffed value rendering + `drawMenu()`, driven entirely by `config.h` |
| `src/touch.cpp` | `cyd`/`round128`/`lcd147`/`lcd147_lvgl`: tap-zone dispatch; XPT2046 (CYD, VSPI), CST816T (round128, I2C), or no-op stub (lcd147 has no touch hardware) |
| `src/panel_round21.cpp` | `round21` + `round21_lvgl`: shared ST7701 init + RGB panel bring-up + backlight PWM, used by both display backends |
| `src/display_round21.cpp` | `round21` (Arduino_GFX): `Arduino_ST7701` GFX subclass over `panel_round21`, layout + diffed rendering + `drawMenu()` |
| `src/display_round21_lvgl.cpp` | `round21_lvgl` (LVGL): flush callback over `panel_round21`, LVGL widget layout + `drawMenu()`, 48px/28px DSEG7 digit fonts |
| `src/touch_round21.cpp` | `round21` + `round21_lvgl`: tap-zone dispatch + CST820 front end, shared unchanged by both |
| `src/tca9554.cpp` | `round21` + `round21_lvgl`: TCA9554 I2C IO-expander driver (panel reset/CS/power, touch reset) |
| `src/display_oled13.cpp` | `oled13` (Adafruit_SH110X): I2C bring-up (with address fallback + bus scan on failure), compact big-value layout + `drawMenu()` |
| `src/touch_oled13.cpp` | `oled13`: unconditional no-op stub — no touch hardware on this board |
| `src/display_lcd147_lvgl.cpp` | `lcd147_lvgl` (LVGL over TFT_eSPI): flush callback via `tft.pushImage()`, LVGL widget layout + `drawMenu()`, 22px/16px DSEG7 digit fonts |
| `include/lv_conf.h` | `round21_lvgl` + `lcd147_lvgl`: shared LVGL config, picked up via each env's `-D LV_CONF_INCLUDE_SIMPLE=1`/`-I include` build flags |
| `lib/dseg7_font/` | `round21_lvgl` + `lcd147_lvgl`: DSEG7 Classic Bold (SIL OFL) converted to LVGL fonts at 48/28/22/16px — see "The round21 board" above |
| `src/main.cpp` | Boot, loop (menu vs. gauge branch), preset names — shared, board-agnostic |

Each env's `build_src_filter` in `platformio.ini` picks the right
`display*`/`touch*` files for its own backend and excludes every other
backend's board-specific files (`tca9554.cpp`/`panel_round21.cpp` on boards
that don't have that hardware, the other board's `display_*_lvgl.cpp`, etc).

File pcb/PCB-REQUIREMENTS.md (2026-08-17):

# PCB Requirements — AirLift V2 + MFL Cruise Input

Scope: a new PCB that carries everything the current AirLift V2 board does
(LIN MITM, CAN/TWAI, ignition sense, high-side driver) **plus** a new input
that reads the BMW E46 steering wheel's MFL cruise-control buttons (RES/+,
SET/-, ON, IO), repurposed to drive AirLift actions since the car's factory
cruise control doesn't work.

This is a requirements list for schematic capture, not a schematic — chip
choices below are either "must match the existing product" (inherited) or
"validated on a bench prototype, final part TBD at layout" (new).

---

## 1. MCU

- **ESP32-WROOM-32**, same module as the existing AirLift V2 / MFSW
  Controller shared PCB.
- Existing board mounts it as a pluggable DevKit-style module (per current
  `platformio.ini` targeting generic `esp32dev`). Carry this forward unless
  there's a specific reason to move to a bare/castellated module — not
  something this doc is deciding.

---

## 2. Inherited subsystems (carry forward from current AirLift V2 PCB)

These already exist on the current board (`PlatformIO/include/defs.h`) and
must be retained as-is unless a change is explicitly wanted:

| Function | GPIO | Notes |
|---|---|---|
| LIN 1 (Controller) TX | 17 | `Serial1`, 9600 8N1 |
| LIN 1 (Controller) RX | 16 | |
| LIN 2 (Manifold) TX | 23 | `Serial2`, 9600 8N1 |
| LIN 2 (Manifold) RX | 22 | |
| LIN transceiver WAKE | 18 | held HIGH for normal operation (TJA1020) |
| LIN transceiver CS/EN | 19 | HIGH = transceivers enabled |
| CAN/TWAI RX | 13 | |
| CAN/TWAI TX | 14 | |
| Ignition sense (aux) | 39 | input-only pin, 12V level, optional hard-wired ignition detect |
| Controller high-side power | 21 | MOSFET/transistor switch, +12V, 5A max |

Associated chips to retain:
- **LIN transceiver(s)**: TJA1020 (per existing firmware comments), one per
  LIN channel (2 total) — WAKE/CS shared per the pin table above.
- **CAN transceiver**: TJA1050 or SN65HVD230 class, TWAI-compatible,
  listen-only capable (driver-level, not necessarily a hardware pin).
- **High-side driver**: transistor/MOSFET stage capable of switching +12V
  at up to 5A to the handheld controller, for the ignition-off air-out
  sequence.
- **12-way main connector** (MX23A12NF1 on current board) — see §5, pins
  11/12 are currently unused and are the natural home for the new MFL wire.

**Important pin conflict to flag**: GPIO18 is already committed to LIN
transceiver WAKE on this board. The MFL bench prototype used GPIO18 because
it was free on a bare, standalone DevKit with nothing else wired to it —
**that pin is not available on the combined board.** See §3 for the
production pin choice.

---

## 3. New subsystem: MFL cruise-button input

### Signal characteristics (bench-verified, see `test/mfl_sniffer/`)

- Single wire, BMW "Datalink MFL" line (wheel connector pin 8 / DME
  connector pin 27) — not present on CAN or K-Line.
- Idle-high, ~9-15V depending on engine/battery state (not 3.3V/5V logic).
- Message = 8 PWM pulses, repeating ~every 10ms.
- Bit encoding: pulse width (~168µs vs ~336µs) — bit threshold ~250µs.
- Decodes to 4 buttons via bitmask (ON, IO, PLUS/RES, MINUS/SET) — firmware
  side, already implemented and confirmed working end-to-end via optocoupler
  isolation.

### Protection / isolation circuit

- **Required**: the ESP32 must never see the car-side ~9-15V (or automotive
  transients above that) directly. Bench-validated approach: 4N35
  optocoupler, R1 (LED current limit, car side) + R2 (pull-up,
  ESP32/3V3 side), both ~510Ω-4.7kΩ, non-critical values.
- **For production**: evaluate an SMD optocoupler (e.g. PC817-series SMD
  variant, or SMD 4N35 equivalent) for board space — confirm switching
  speed is adequate for ~170µs pulse widths (comfortably true for this
  device class, but verify against the specific part's datasheet).
- **Open item — transient robustness**: bench testing only validated normal
  running-range voltage (~9-15V). This wire runs through the steering
  column/clockspring; if it should also survive automotive load-dump or
  ESD-class transients (ISO 7637-2 style pulses), add a TVS clamp ahead of
  R1, sized to the optocoupler's input rating. Not yet a confirmed
  requirement — flag for decision before layout.
- Car-side ground for this signal is the **same vehicle chassis ground**
  already used by LIN/CAN/ignition-sense elsewhere on this board (unlike
  the bench test's two separate breadboards) — no separate ground domain
  needed on the PCB itself. The optocoupler is still worth keeping for
  voltage protection and noise immunity, just not for avoiding a ground
  loop that doesn't exist on a single board.

### GPIO assignment

- **Do not use GPIO18** (see §2 conflict).
- Recommend an input-only pin, consistent with how `pinIgnitionSense` (39)
  was chosen on the existing board: **GPIO34, 35, or 36** are free, have no
  internal pull, and can't be accidentally driven as an output. GPIO34 is
  the suggested default.
- Must remain edge-interrupt capable (true for any ESP32 GPIO) — no other
  special requirement (not ADC-sampled, not touch-capable, no RTC/wake
  requirement identified yet — see open item below).

### Connector

- Add **one pin** for the MFL signal wire — connector pins 11/12 on the
  current 12-way MX23A12NF1 are unused and unassigned; use one of those.
  No new ground pin needed (reuse pin 2, `GND`).

### Firmware-side note (not a PCB item, but affects pin choice)

- Existing power management never light-sleeps the ESP32 (per README), so
  the MFL GPIO doesn't currently need wake-source capability. **Open
  question**: should a button press also count as a "wake" event the way a
  CAN burst does? If yes in the future, confirm the chosen GPIO supports
  whatever wake mechanism is used before finalizing.

---

## 4. Power

- Board is powered from switched 12V (`PWR_IN`, connector pin 1), same as
  current design. Existing regulation chain (5V/3.3V for ESP32 + logic) is
  inherited as-is — no changes identified for this feature; confirm the
  existing regulator has enough margin for the added optocoupler LED
  current (a few mA, negligible) — not expected to matter but worth a
  one-line sign-off during schematic review.

---

## 5. Mechanical / connector summary

| Pin | Signal | Status |
|---|---|---|
| 1 | `PWR_IN` | existing |
| 2 | `GND` | existing — also serves as MFL signal return |
| 3 | `LIN1` | existing |
| 4 | `LIN2` | existing |
| 5 | `CHASSIS_CANH` | existing |
| 6 | `CHASSIS_CANL` | existing |
| 7 | `ANALOG_LIGHT_IN` | existing (ignition sense) |
| 8 | `RA` | existing, unpopulated |
| 9 | `5V` | existing |
| 10 | `OUTPUT1` | existing (controller high-side) |
| 11 | **`MFL_SIGNAL`** | **new — this feature** |
| 12 | — | still unused |

---

## 6. Open questions before schematic capture

1. TVS/transient clamp on the MFL line — required or not? (§3)
2. Final optocoupler part number (DIP-6 4N35 vs SMD equivalent) and R1/R2
   values for that part.
3. Whether MFL button presses should participate in wake/power-management
   logic alongside CAN traffic.
4. Button → action mapping is a firmware decision, not a PCB one, but
   worth confirming before finalizing: PLUS/MINUS → air-up/air-down (as
   discussed), ON/IO → cycle presets or unassigned.

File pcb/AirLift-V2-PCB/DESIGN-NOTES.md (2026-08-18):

# AirLift V2 + MFL Controller — PCB Design Notes

Generated PCB (schematic + layout + routing) for the AirLift V2 + MFL controller,
built from `AirLift-V2-PCB-DesignSpec.md`. This file documents judgment calls,
known warnings, and items a human should verify before sending to fab.

## Status

- Schematic: **ERC clean — 0 errors**, 6 cosmetic `lib_symbol_mismatch` warnings
  (embedded copies of stock diode/transistor symbols differ trivially from the
  live library copies; harmless, does not affect netlist or fab).
- PCB: **DRC clean — 0 errors, 0 unconnected nets**, 2 cosmetic warnings
  (`silk_overlap` / `silk_over_copper` between Q_REV's silkscreen and C_BULK's
  reference designator text — purely visual, does not affect fabrication or
  assembly; can be nudged in the GUI if desired).
- Board size: ~130 x 115 mm (compact — down from an original 247 x 104 mm
  strip, then a 156 x 149 mm grid, tightened further by packing more zones
  in 2 sub-columns and shrinking the gap between functional blocks from
  10mm to 6.5mm). Components are grouped into a functional grid: connector +
  power protection + output driver in one column near the harness connector,
  the ESP32 DevKit carrier as a central spine, LIN/CAN bus transceivers
  grouped together, and the MFL optocoupler + ignition-sense analog inputs
  kept farthest from the power/switching section. The layout is now solved
  programmatically from each zone's real footprint bounding box (see
  `_solve_grid()` in `build_pcb.py`) rather than hand-tuned coordinates, so
  further size/spacing tweaks (edit `GAP`/`MARGIN` at the top of that file)
  automatically reflow the whole board without manual recalculation. The
  schematic mirrors the same grouping with a 3x3 grid of function blocks
  (was previously a single row spanning 2 meters).
- High-current nets (PWR_IN, +12V_PROT, OUTPUT1 — rated up to 5A) are routed on
  a dedicated `Power5A` netclass at **1.5mm trace width / 0.3mm clearance**;
  all other signal/logic nets use the default 0.2mm class.

## Judgment calls made during design

1. **Reverse-battery protection**: implemented as a P-MOSFET "ideal diode"
   (Q_REV = IRF4905, gate pulled to GND via 10k) rather than a series diode,
   to avoid the ~0.5-0.7V forward-drop heat dissipation at up to 5A that a
   diode would incur.
2. **3.3V rail**: added a local AMS1117-3.3 LDO (U_33) rather than relying on
   the ESP32 DevKit's onboard 3.3V regulator/pin, since the devkit's own
   regulator may not have headroom for additional board loads (LIN/CAN
   transceivers, optocoupler pull-ups, etc.) — this was not explicitly
   specified in the requirements doc and is a conservative addition.
3. **MFL input isolation**: PC817 optocoupler (U_OPTO) plus a TVS clamp
   (SMAJ26A, D3) on the car-side input, with a 1k series resistor (R1) sized
   for a nominal 12V input into the optocoupler LED. Verify R1/R2 values
   against your actual MFL button voltage divider before final assembly —
   the spec's MFL signal characteristics were not fully pinned down.
4. **Ignition-sense input**: resistor divider (R9/R10) with a zener clamp
   (D_Z1, BZX84C3V6) sized to the DevKit's ADC input range, since alternator
   ripple can exceed 15V transiently.
5. **Extends-based symbols flattened**: IRF4905 and other library symbols
   that use KiCad's `extends` (symbol inheritance) were flattened (base
   symbol's graphics/pins copied directly in) because `kicad-cli` 9.0.9's
   headless ERC fails to load schematics containing `extends`-based symbols.
   This is a tooling workaround, not a functional/electrical change — it is
   the source of the 6 cosmetic `lib_symbol_mismatch` ERC warnings above.

## Known open items — please review before fab

1. **ESP32 DevKit header spacing — MUST BE MEASURED ON YOUR BOARD (blocking)**:
   `J_DEVKIT_L`/`J_DEVKIT_R` are two 1x15 female sockets meant to receive the
   DevKit's two male pin rows like a socketed shield. They are placed
   side-by-side, pin-1-to-pin-1 aligned (confirmed correct against the DOIT
   ESP32 DevKit V1 pinout), spaced **25.4mm (1.00") center-to-center** —
   but that number is an **unconfirmed placeholder**, not a verified
   datasheet value. "ESP32 DevKit V1" is sold under one name by many
   vendors with genuinely different board widths (checking two independent
   pinout references for nominally the same board turned up 28.2mm and
   23.37mm overall board width, respectively — a real, well-known mismatch
   between clones). If the real spacing on your physical board differs from
   25.4mm even by a millimeter, the DevKit will not seat in these sockets.
   **Before fab: measure center-to-center pin spacing on your actual board
   with calipers** (or count grid holes if you know the pitch) and tell me
   the number so I can correct `DEVKIT_ROW_SPACING_MM` in `build_pcb.py`
   and re-route.
2. **Connector current rating vs. spec (needs your decision)**: the requirements
   doc specifies up to 5A on `OUTPUT1` (J1 pin 10), but the connector used
   (JAE MX23A12NF1, 2.5mm pitch, 2x6, right-angle) is rated **3A per contact**
   per its datasheet. Options: (a) confirm 5A is actually a transient/peak
   rating your load never sustains, (b) parallel two contacts for OUTPUT1 if
   the connector pinout allows it, or (c) switch to a connector family rated
   ≥5A per contact. This was flagged in the original design spec and is not
   resolved in this layout — the board currently routes OUTPUT1 as a single
   3A-rated contact carrying a 5A-spec load.
3. **Custom/unverified footprint**: `AirLift_Custom:MX23A12NF1_2x6_P2.50mm_RA`
   was hand-built from the JAE MX23A12NF1 datasheet drawing and has **not**
   been verified against a real part or manufacturer footprint library.
   Recommend cross-checking pad size/pitch/keepout against the datasheet (or
   ordering the connector and doing a fit-check) before committing to fab.
4. **MFL divider values (R1/R2) and IGN divider values (R9/R10)** are
   reasonable placeholders based on typical automotive signal levels — verify
   against actual measured signals from the target vehicle harness.
5. **Cosmetic silkscreen overlap** near Q_REV/C_BULK (see Status above) — no
   functional impact, but worth a quick nudge in the KiCad GUI if you want a
   cleaner silkscreen for the first article.
6. **Reference designators use a descriptive naming scheme** (e.g. `U_LIN1`,
   `Q_REV`, `C_BULK` instead of `U1`, `Q1`, `C1`) for readability during
   design. These are valid KiCad references, but some BOM tools flag
   non-numeric-suffixed refs as "unannotated" (shown as e.g. `C_BULK?` in the
   exported BOM). This is cosmetic — nets and footprints are correctly
   assigned regardless — but if your fab/assembly house wants strictly
   sequential `U1, U2, ...`-style refs, run KiCad's "Annotate Schematic" tool
   before ordering.
7. **Isolation clearance around the MFL optocoupler barrier**: the design
   spec calls for keeping car-side (9-15V) and MCU-side (3.3V) copper
   separated across U_OPTO. Component placement keeps the two sides in
   separate zones, but the routed board has not been given a manual
   creepage/clearance audit beyond the standard DRC clearance rules — worth
   a visual check in the KiCad 3D/layer viewer before fab if this will see
   real automotive transients.

## Deliverables in this package

- `AirLift-V2-PCB.kicad_sch` / `.kicad_pcb` / `.kicad_pro` — full KiCad 9 project
- `AirLift_Custom.kicad_sym` / `AirLift_Custom.pretty/` — custom TJA1020 symbol
  and MX23A12NF1 footprint
- `deliverables/gerbers.zip` — Gerber (RS-274X) + Excellon drill files
- `deliverables/BOM.csv` — bill of materials (Reference, Value, Footprint)
- `deliverables/pick_and_place.csv` — component placement (pos) file, both sides
- `deliverables/pdf/schematic.pdf` — full schematic printout
- `deliverables/pdf/board.pdf` — board layer printout (Cu/silk/mask/edge)
- `routed_final_render.png` — 3D render of the finished, routed board

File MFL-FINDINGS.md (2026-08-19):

# MFL Cruise-Button Findings

Summary of everything confirmed while getting BMW E46 steering-wheel MFL
cruise-control buttons (RES/+, SET/-, ON, IO) reading reliably into an
ESP32, ahead of folding this into the main AirLift firmware. Bench
prototype and working code: [`test/mfl_sniffer/`](test/mfl_sniffer/). PCB
requirements derived from this: [`pcb/PCB-REQUIREMENTS.md`](pcb/PCB-REQUIREMENTS.md).

---

## What the signal actually is

E46-era BMW cruise buttons do **not** appear on CAN or K-Line. They run
over one dedicated wire straight from the steering wheel to the DME:

- Wheel-side connector: pin 8, "Datalink MFL"
- DME-side: connector `X60004` pin 27, same label
- Route: `DME → X60531 → X6011 → clockspring on the steering column`

(Pin numbers sourced from an M3/MS S54-era wiring reference — cross-check
against your exact chassis/engine if wiring a different car.)

The wheel has its own internal microcontroller that reads the physical
button switches and re-encodes them onto this single wire as a **PWM pulse
train** — it is not a raw switch/resistor-ladder signal on this wire, and
it is not a standard bus protocol (not LIN, not K-Line, not UART-framed).

## Protocol

Decode logic ported from pazi88's `MFL.ino`/`MFL.h`
([Speeduino-M5x-PCBs](https://github.com/pazi88/Speeduino-M5x-PCBs/blob/master/m52tu-m54_PnP/Serial3toBMWcan/MFL.ino)),
which reads the same signal on M52TU/M54 (E46-era) BMWs for ECU-swap
projects — confirmed working end-to-end on this specific car.

- Idle-high line. A message is **8 pulses**, repeating **~every 10ms**.
- Each pulse's HIGH duration encodes a bit. Measured on this car: ~168µs
  and ~341µs are the two widths (threshold at the midpoint, 250µs).
- Pulse 8 (index 7) is a toggle/counter bit, not part of the decoded value.
- A HIGH duration **> 5ms** marks the idle gap between messages (frame
  sync).
- The first 7 pulses reconstruct a 7-bit value, checked against bitmasks:
  ```
  CRUISE_ON    = (value & 110) == 0
  CRUISE_IO    = (value & 218) == 0
  CRUISE_PLUS  = (value & 182) == 0
  CRUISE_MINUS = (value & 252) == 0
  ```

### Bit polarity — corrected from the original source

pazi88's original hardware (bare GPIO, no inverting stage) treats a **long**
pulse as bit `1`. On this build, with the signal passing through an
inverting isolation stage (see below), the opposite is true: **short pulse
(< threshold) = bit `1`**. This was confirmed by hand-decoding real
captures — long-pulse=1 never produced a valid mask match on any observed
button press; short-pulse=1 produced clean, repeatable matches. If this
logic is ever reused with a *non-inverting* interface, that bit needs
flipping back.

### Idle vs. pressed reading

At rest, the decoded value is `0`, which trivially satisfies all four
bitmasks — naive decoding reads idle as **all four flags `true`
simultaneously** (`ON=1 IO=1 PLUS=1 MINUS=1`). A real button press clears
bits belonging to the *other* three masks while leaving its own mask's bits
untouched, so a press produces a **nonzero** value where exactly one mask
still matches.

**Fixed in `decode()`**: `value == 0` is checked first and returned as "no
button pressed" (all four flags `false`) before the mask checks run, since
every idle capture decoded to exactly `0` and every real press decoded to
something nonzero. Without this check, idle would read as all four buttons
held down at once — clearly wrong, and dangerous if wired to real actions
(triggering air-up and air-down simultaneously, for instance).

**For the AirLift integration**, go one step further than the bench
sniffer does: after excluding `value == 0`, still only trust a decode where
*exactly one* of the four flags is `true`. This is based on four observed
button presses, not a proof from the bitmask structure itself — a
corrupted/noisy frame on a real automotive bus could in principle produce
an unexpected value that matches zero or more than one mask. Since this
will be triggering physical air-up/air-down actions, treat "not exactly one
match" as a discard-this-frame case rather than acting on it.

## Confirmed button mapping (this car, single-press-per-button test)

| Physical button | Flag that stays `1` while the other three drop to `0` |
|---|---|
| + | `PLUS` |
| − | `MINUS` |
| SET | `ON` |
| IO | `IO` |

Three of four line up with pazi88's flag names directly. One real finding:
**this wheel's "SET" button decodes as `CRUISE_ON`, not `CRUISE_MINUS`.**
The flag names are just labels from the original author's car and don't
necessarily match this wheel's silkscreen — when folding into AirLift,
name the resulting firmware fields after the physical button (`mflPlus`,
`mflMinus`, `mflSet`, `mflIo` or similar), not after pazi88's internal
names, to avoid future confusion.

## Electrical

- Idle voltage on this car: **~10.0V** (not 3.3V/5V logic) — rides on the
  vehicle's 12V-class rail, expected to vary ~9-15V with engine/battery
  state.
- **Isolation/protection circuit**: 4N35 optocoupler. Car side: signal
  through R1 (~510Ω, non-critical) into the LED anode, cathode to car
  ground. ESP32 side: 3V3 through R2 (~510Ω) pull-up into the
  phototransistor collector (read by the GPIO), emitter to ESP32 ground.
  Full writeup and wiring diagram history in
  [`test/mfl_sniffer/README.md`](test/mfl_sniffer/README.md).
- This inverts the signal (car HIGH → LED on → phototransistor on → GPIO
  pulled LOW) — accounted for in both the framing code (`kSignalInverted`)
  and the bit-polarity fix above.
- On the bench prototype, GPIO18 was used and works fine. **On the real
  AirLift PCB this conflicts** with the existing LIN transceiver WAKE pin
  — production wiring needs a different, genuinely free GPIO (GPIO34
  recommended; see `pcb/PCB-REQUIREMENTS.md`).

## Next steps (firmware integration)

1. ~~Port the framing/decode logic from `test/mfl_sniffer/src/main.cpp` into
   the main AirLift firmware as its own module, rather than copy-pasting
   into existing files.~~ **Done** — `PlatformIO/include/mfl.h` /
   `src/mfl.cpp`, on the production pin (GPIO34, see point 5 below).
2. ~~Rename the decoded fields to match physical buttons (see mapping
   table), not pazi88's original flag names.~~ **Done** — `MflButtons` in
   `mfl.h` uses `plus`/`minus`/`set`/`io`, with a comment noting this wheel's
   "SET" decodes as pazi88's `on` mask.
3. Button → action mapping: **implemented differently from the original
   plan.** Rather than PLUS/MINUS driving air up/down directly, all four
   buttons now drive an on-screen menu on the Slave Display (`IO` =
   enter/select, `PLUS`/`MINUS` = up/down, `SET` = back), with **preset
   select** as the only action that reaches the manifold so far — see
   `SlaveDisplay/include/menu.h` and `AirLiftButtons`/`AirLiftCommand` in
   `airlift_espnow.h`. Direct air up/down on PLUS/MINUS (bypassing the menu)
   remains an open option if the menu proves too slow for that.
4. Still open: whether an MFL button press should participate in the
   existing power-management wake logic alongside CAN traffic (currently the
   ESP32 never light-sleeps, so this may be moot — revisit if that changes).
5. ~~Move from the bench GPIO (18) to the production pin once the new PCB
   pin map is finalized.~~ **Done** — GPIO34, confirmed on the fabricated
   PCB's net list (`MFL_SIGNAL` → optocoupler → `MFL_IN` → `J_DEVKIT_L` pin
   4) and set as `pinMflSignal` in `PlatformIO/include/defs.h`.

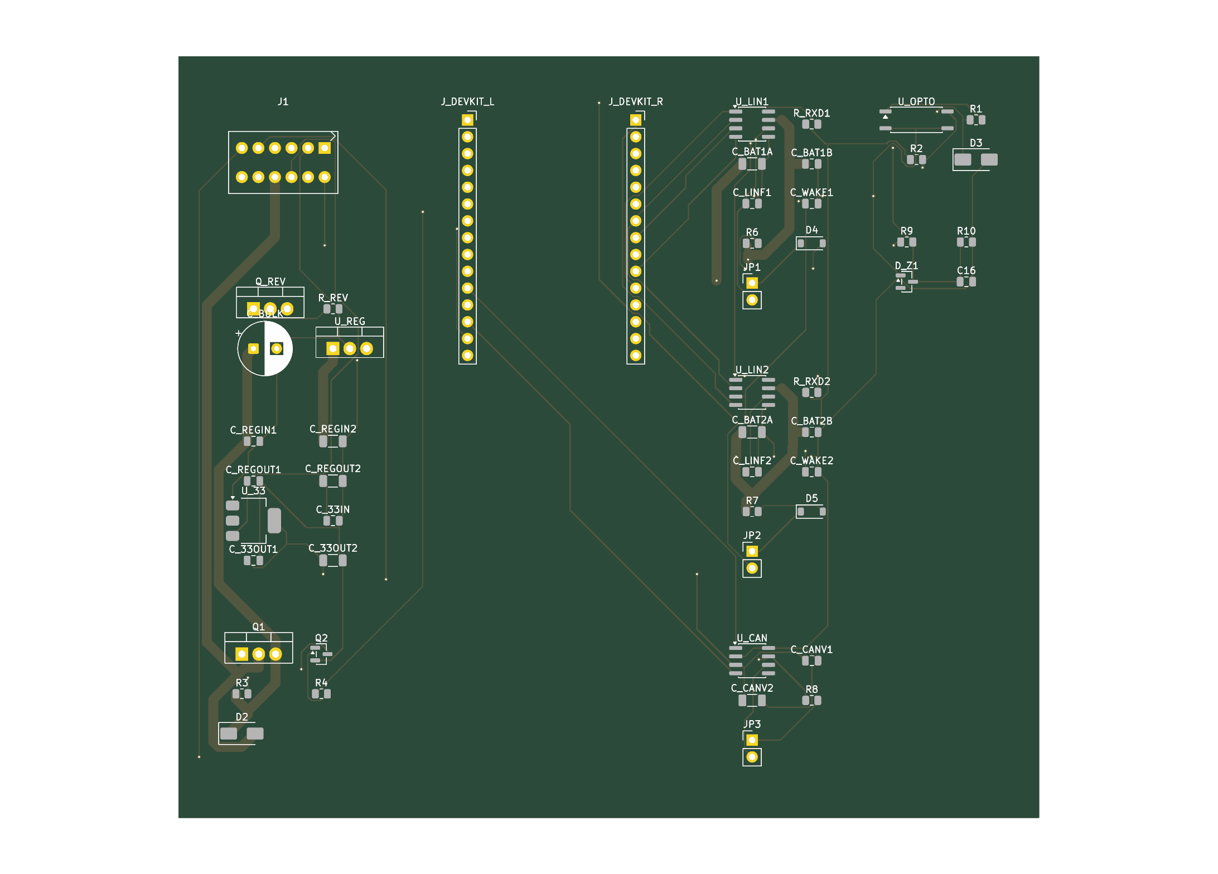
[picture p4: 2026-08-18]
pcb/AirLift-V2-PCB/routed_final_render.png

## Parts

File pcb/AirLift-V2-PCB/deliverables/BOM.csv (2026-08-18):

Reference | Value | Footprint | Datasheet
C16 | 100nF | Capacitor_SMD:C_0805_2012Metric
C_33IN? | 100nF | Capacitor_SMD:C_0805_2012Metric
C_33OUT1 | 100nF | Capacitor_SMD:C_0805_2012Metric
C_33OUT2 | 10uF | Capacitor_SMD:C_1206_3216Metric
C_BAT1A? | 10uF | Capacitor_SMD:C_1206_3216Metric
C_BAT1B? | 100nF | Capacitor_SMD:C_0805_2012Metric
C_BAT2A? | 10uF | Capacitor_SMD:C_1206_3216Metric
C_BAT2B? | 100nF | Capacitor_SMD:C_0805_2012Metric
C_BULK? | 100uF | Capacitor_THT:CP_Radial_D8.0mm_P3.50mm
C_CANV1 | 100nF | Capacitor_SMD:C_0805_2012Metric
C_CANV2 | 1uF | Capacitor_SMD:C_1206_3216Metric
C_LINF1 | 1nF | Capacitor_SMD:C_0805_2012Metric
C_LINF2 | 1nF | Capacitor_SMD:C_0805_2012Metric
C_REGIN1 | 100nF | Capacitor_SMD:C_0805_2012Metric
C_REGIN2 | 10uF | Capacitor_SMD:C_1206_3216Metric
C_REGOUT1 | 100nF | Capacitor_SMD:C_0805_2012Metric
C_REGOUT2 | 10uF | Capacitor_SMD:C_1206_3216Metric
C_WAKE1 | 220pF | Capacitor_SMD:C_0805_2012Metric
C_WAKE2 | 220pF | Capacitor_SMD:C_0805_2012Metric
D2 | SS34 | Diode_SMD:D_SMA
D3 | SMAJ26A | Diode_SMD:D_SMA
D4 | 1N4148 | Diode_SMD:D_SOD-123
D5 | 1N4148 | Diode_SMD:D_SOD-123
D_Z1 | BZX84C3V6 | Package_TO_SOT_SMD:SOT-23
J1 | MX23A12NF1 | AirLift_Custom:MX23A12NF1_2x6_P2.50mm_RA
JP1 | LIN1_MASTER | Connector_PinHeader_2.54mm:PinHeader_1x02_P2.54mm_Vertical
JP2 | LIN2_MASTER | Connector_PinHeader_2.54mm:PinHeader_1x02_P2.54mm_Vertical
JP3 | R_TERM1 | Connector_PinHeader_2.54mm:PinHeader_1x02_P2.54mm_Vertical
J_DEVKIT_L? | ESP32_DevKit_L | Connector_PinSocket_2.54mm:PinSocket_1x15_P2.54mm_Vertical
J_DEVKIT_R? | ESP32_DevKit_R | Connector_PinSocket_2.54mm:PinSocket_1x15_P2.54mm_Vertical
Q1 | IRF4905 | Package_TO_SOT_THT:TO-220-3_Vertical
Q2 | MMBT3904 | Package_TO_SOT_SMD:SOT-23
Q_REV? | IRF4905 | Package_TO_SOT_THT:TO-220-3_Vertical
R1 | 1k | Resistor_SMD:R_0805_2012Metric
R2 | 4.7k | Resistor_SMD:R_0805_2012Metric
R3 | 10k | Resistor_SMD:R_0805_2012Metric
R4 | 4.7k | Resistor_SMD:R_0805_2012Metric
R6 | 1k | Resistor_SMD:R_0805_2012Metric
R7 | 1k | Resistor_SMD:R_0805_2012Metric
R8 | 120 | Resistor_SMD:R_0805_2012Metric
R9 | 10k | Resistor_SMD:R_0805_2012Metric
R10 | 3.3k | Resistor_SMD:R_0805_2012Metric
R_REV? | 10k | Resistor_SMD:R_0805_2012Metric
R_RXD1 | 10k | Resistor_SMD:R_0805_2012Metric
R_RXD2 | 10k | Resistor_SMD:R_0805_2012Metric
U_33 | AMS1117-3.3 | Package_TO_SOT_SMD:SOT-223-3_TabPin2
U_CAN? | SN65HVD230 | Package_SO:SOIC-8_3.9x4.9mm_P1.27mm
U_LIN1 | TJA1020 | Package_SO:SOIC-8_3.9x4.9mm_P1.27mm
U_LIN2 | TJA1020 | Package_SO:SOIC-8_3.9x4.9mm_P1.27mm
U_OPTO? | PC817 | Package_SO:SO-4_7.6x3.6mm_P2.54mm
U_REG? | L7805 | Package_TO_SOT_THT:TO-220-3_Vertical

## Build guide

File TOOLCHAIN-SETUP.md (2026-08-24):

# Toolchain Setup — Machine Handover Reference

Exact tooling/versions from a machine that successfully builds and flashes
every env in this repo (master `PlatformIO/`, `SlaveDisplay/`, and the
`test/*` bench rigs). If a build/flash works here but not on another
machine, compare against this first before assuming a code or hardware
problem.

## The one thing most likely to bite you

Every `platformio.ini` in this repo declares:

```ini
platform = espressif32
```

**unpinned** — no version, no URL. On this machine, that unpinned name
resolves to the **pioarduino community fork**, not the official PlatformIO
registry platform:

```
PLATFORM: Espressif 32 (53.3.10)
  (https://github.com/pioarduino/platform-espressif32/releases/download/53.03.10/platform-espressif32.zip)
```

confirmed identical across every env in every project in this repo (master,
all five `SlaveDisplay` boards, `test/can_sniffer`, `test/mfl_sniffer`).
That's because this fork was explicitly installed at some point and
PlatformIO's resolver picks it as the highest-versioned match for the bare
`espressif32` name — nothing in the repo's `.ini` files forces this.

**On a fresh machine that has never installed the pioarduino fork, `pio run`
will instead pull whatever the official `platformio/espressif32` registry
entry currently is** — a different platform, likely bundling an older
Arduino-ESP32 core. This matters a lot here: native USB-CDC on the ESP32-S3
boards (`round21`, `oled13`, `lcd147`), `ledcAttach()`/`neopixelWrite()`, and
other Arduino-ESP32 3.x APIs used throughout this codebase need that core
version. An older core can fail to build, or build something that can't
enter/complete a flash upload correctly — exactly the "can't flash" symptom
this doc exists to rule out.

**Fix / verify**, before troubleshooting anything else:

```bash
pio pkg install -g -p "https://github.com/pioarduino/platform-espressif32/releases/download/53.03.10/platform-espressif32.zip"
pio run -e <any env> -v 2>&1 | grep '^PLATFORM:'
```

The output must say `Espressif 32 (53.3.10)` with that pioarduino URL, not a
bare `(6.x.x)` official-registry version. If it doesn't match, that's very
likely the root cause of a flash/build failure that only happens on one
machine.

## Exact versions (this machine)

| Tool | Version |
|---|---|
| PlatformIO Core | 6.1.18 |
| Python (pio's venv, `~/.platformio/penv`) | 3.11.7 |
| esptool.py | 4.8.5 (pioarduino's build, bundled with the platform above) |
| espressif32 platform | 53.3.10 (pioarduino fork — see above) |
| framework-arduinoespressif32 (Arduino-ESP32 core) | 3.1.0 |
| framework-arduinoespressif32-libs (ESP-IDF) | 5.3.0+sha.083aad99cf (IDF 5.3) |
| toolchain-xtensa-esp-elf | 13.2.0+20240530 |
| macOS | 26.5.1 (build 25F80) |

These are what every env in this repo actually built against when last
verified (checked via `pio run -e <env> -v`, not just what's installed
globally — this machine has several other espressif32/framework versions
installed too, from other projects; they're irrelevant here as long as the
platform line above matches).

## Per-project library versions (as resolved by `pio run -v`)

**`PlatformIO/` (master)**
| Library | Version |
|---|---|
| AsyncTCP (ESP32Async/AsyncTCP) | 3.5.0 |
| ESPAsyncWebServer (ESP32Async/ESPAsyncWebServer) | 3.12.0 |
| ArduinoJson (bblanchon/ArduinoJson) | 7.4.3 |
| LittleFS / Update / WiFi | 3.1.0 (bundled with the Arduino core) |

**`SlaveDisplay/`** (per env — only the env's own display library, plus the
core's bundled WiFi/SPI/Wire)
| Env | Library | Version |
|---|---|---|
| `cyd` | TFT_eSPI (bodmer) | 2.5.43 |
| `cyd` | XPT2046_Touchscreen (git: PaulStoffregen/XPT2046_Touchscreen) | 1.4.0+sha.f956c5d |
| `round128` | TFT_eSPI (bodmer) | 2.5.43 |
| `round128` | CST816S (fbiego) | 1.3.0 |
| `round21` | GFX Library for Arduino (moononournation) | 1.6.7 |
| `round21_lvgl` | lvgl/lvgl | 9.5.0 |
| `oled13` | Adafruit SH110X | 2.1.15 |
| `oled13` | Adafruit GFX Library | 1.12.6 |
| `oled13` | Adafruit BusIO | 1.17.4 |
| `lcd147` | TFT_eSPI (bodmer) | 2.5.43 |
| `lcd147_lvgl` | TFT_eSPI (bodmer) | 2.5.43 |
| `lcd147_lvgl` | lvgl/lvgl | 9.5.0 |

**`test/*` bench rigs** — `can_sniffer`, `mfl_sniffer`, `stepper_sweep` use
only core libraries (WiFi, esp_now, esp_wifi, driver/twai), no extra
`lib_deps`.

## Board / upload settings quick-reference

| Project / env | `board` | Upload path | `upload_speed` | Flash notes |
|---|---|---|---|---|
| `PlatformIO/` (master) | `esp32dev` | CH340-style USB-UART bridge (port shows as `cu.usbserial-*`) | default (unset) | — |
| `SlaveDisplay` `cyd` | `esp32dev` | CH340-style bridge | **460800** (pinned — this board's CH340 drops the esptool stub handshake at the default 921600) | — |
| `SlaveDisplay` `round128` | `esp32-s3-devkitc-1` | native USB (`cu.usbmodem*`) | 921600 | `board_upload.flash_size=16MB`, `board_build.flash_mode=qio` |
| `SlaveDisplay` `round21` | `esp32-s3-devkitc-1` | native USB | 921600 | qio_opi PSRAM config — see platformio.ini comments |
| `SlaveDisplay` `round21_lvgl` | `esp32-s3-devkitc-1` | native USB | 921600 | Same qio_opi PSRAM config as `round21` — LVGL rendering backend, same board |
| `SlaveDisplay` `oled13` | `esp32-s3-devkitc-1` | native USB | 921600 | — |
| `SlaveDisplay` `lcd147` | `esp32-s3-devkitc-1` | native USB | 921600 | `board_upload.flash_size=16MB`, `board_build.flash_mode=qio` |
| `SlaveDisplay` `lcd147_lvgl` | `esp32-s3-devkitc-1` | native USB | 921600 | Same flash settings as `lcd147` — LVGL rendering backend, same board |
| `test/can_sniffer`, `test/mfl_sniffer` | `esp32dev` | CH340-style bridge | default | — |
| `test/stepper_sweep` | `esp32-s3-devkitc-1` | native USB | 115200 | — |

**Native-USB ESP32-S3 boards** (`round21`, `oled13`, `lcd147`, and
`stepper_sweep`) enumerate as `/dev/cu.usbmodem*` on macOS and need no
driver. **CH340-bridge boards** (master, `cyd`, `can_sniffer`,
`mfl_sniffer`) enumerate as `/dev/cu.usbserial-*` — modern macOS (Ventura+)
has this built in natively; nothing to install.

## macOS auto-reset quirk (if serial capture looks empty)

Opening a fresh serial connection to an already-running native-USB-CDC
ESP32-S3 board does **not** reliably show its live output — only a
connection that also toggles RTS/DTR to trigger a genuine reset reliably
captures anything, and only from that reset point forward. If a live
serial monitor looks silent on a board you know is running, reset it
(physical button, or a monitor tool that pulses RTS) rather than assuming
nothing's happening.

## `pio run -v` sanity check

To confirm a machine matches this doc for a given env:

```bash
cd SlaveDisplay   # or PlatformIO, or test/<rig>
pio run -e <env> -v 2>&1 | grep -E '^PLATFORM:|^PACKAGES:| - '
```

Compare the `PLATFORM:` line and package list against the tables above.

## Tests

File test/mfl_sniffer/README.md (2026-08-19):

# MFL cruise-control sniffer (bench test)

Throwaway rig to confirm the BMW MFL cruise-control signal exists on your car
and matches the known protocol, **before** wiring it into anything permanent
or committing to a PCB layout. Not part of the AirLift firmware.

## What you're tapping

On E46/E39-era BMWs the steering-wheel cruise buttons (RES/+, SET/-, ON/OFF)
do **not** go over CAN or K-Line — they go over one dedicated wire straight
from the steering wheel to the DME:

- Wheel-side connector: pin 8, "Datalink MFL"
- DME-side: connector `X60004` pin 27, same label
- Route: `DME → X60531 → X6011 → clockspring on the steering column`

Pin numbers above came from an M3/MS S54-era wiring reference — cross-check
against your actual chassis/engine wiring diagram before you cut into
anything, connector pinouts shift a bit by year/harness.

## Before connecting anything: measure it

With a multimeter, key on, probe the Datalink MFL wire to chassis ground:

1. Idle voltage (no buttons pressed).
2. Voltage while holding a button.

Write both down.

**Measured on this car: idle ~10.0V, dips to ~9.5-9.7V on IO/SET while held,
barely moves on PLUS/MINUS.** That's expected, not a measurement error — a
multimeter averages, and this signal is high almost all the time with only
brief (~150-350us) low pulses during each ~10ms message. Different buttons
encode different bit patterns, so the DC average dips by different (small)
amounts per button. This is actually consistent with the protocol, not
evidence against it. Don't try to identify buttons from the multimeter —
that's what the sniffer's raw pulse dump is for.

The important number here is the **idle level, ~10V** — this is riding on
the car's 12V-class rail, not 3.3V/5V logic. That rules out a plain
diode-clamp approach: the signal sits high almost continuously, so a clamp
diode would be conducting nearly all the time, holding the pin at a
sustained out-of-spec voltage rather than just catching brief transients.
It also means the exact voltage will drift with engine state (resting
battery vs. alternator running, roughly 9-15V depending on conditions) —
so the circuit needs to tolerate a range, not one measured number.

## Protection circuit: 4N35 optocoupler (what this bench build actually uses)

Fully decouples the ESP32 from the car's voltage domain — no shared ground
required between the two sides, which is stronger isolation than a resistor
divider or a plain transistor level-shifter:

```
Car MFL wire ──/\/\/\── Pin 1 (Anode)
              R1 (510Ω)
                        [4N35]
Car GND ──────────────── Pin 2 (Cathode)

ESP32 3V3 ── R2 (510Ω, pull-up) ──┬── Pin 5 (Collector)
                                    │
                               ESP32 GPIO (this build: D18)

ESP32 GND ─────────────────────────── Pin 4 (Emitter)
```

DIP-6 pinout: 1 Anode, 2 Cathode, 3 NC, 4 Emitter, 5 Collector, 6 Base (leave
6 and 3 unconnected). Check your own part's pin-1 dot before inserting —
DIP orientation isn't universal; this build's part lands pin 1 at top-right
when straddling the breadboard's center gap, not top-left.

- R1 (LED side, car-facing) and R2 (phototransistor side, ESP32-facing) only
  need to be roughly 1kΩ–4.7kΩ — not picky. This build used 510Ω for both
  (green-brown-brown-gold), which is a bit more current than ideal but well
  within safe limits for the 4N35 and the ESP32.
- Pins 1-2 (car side) and pins 4-5 (ESP32 side) share **no electrical node**
  — only light crosses between them. Tie pin 2 to car chassis ground and
  pin 4 to ESP32 ground; these can be two genuinely separate references.
- **This inverts the signal**: car HIGH → LED on → phototransistor on → GPIO
  pulled LOW. `src/main.cpp` has `kSignalInverted = true` set for this.
- Keep car-side wiring (R1, pins 1/2) physically separate from ESP32-side
  wiring (R2, pins 4/5, GPIO, 3V3) while building — nothing should bridge
  directly between them except the 4N35 itself.

### Alternatives, if you don't have a 4N35

**NPN transistor level-shifter** (any 2N3904/2N2222/BC547 + two ~10k
resistors): base through a resistor to the car wire, emitter to GND,
collector to the GPIO with a pull-up to 3V3. Also inverting, but shares
ground between the two sides rather than isolating them.

**Divider + zener clamp**, if you have a 3.3V zener (e.g. BZX55C3V3) but no
transistor or optocoupler: a divider (try 6.8kΩ from car wire to node, 3.3kΩ
from node to GND) with the zener across the 3.3kΩ leg. Non-inverting — leave
`kSignalInverted = false`. A plain divider with **no** clamp is not safe
here: satisfying both "valid logic-high at ~9-10V" and "under the ESP32's
3.6V abs max at ~14-15V" isn't possible with fixed resistors alone over that
range.

`kMflPin` in `main.cpp` selects the GPIO — set it to whichever pin you
actually wired.

## Running it

```
cd test/mfl_sniffer
pio run -t upload
pio device monitor
```

(Needs [PlatformIO](https://platformio.org/); `platformio.ini` targets a
generic `esp32dev` board like the rest of this repo.)

## Reading the output

Each line is one decoded message:

```
[172,340,168,335,170,169,338,4820] ON=0 IO=0 PLUS=1 MINUS=0   <-- CONFIRMED CHANGE
```

- The `[...]` is the 8 raw pulse widths in microseconds, in order — this is
  what you actually want to look at first. Confirm you're seeing something
  in the ~150-350us range for the first 7, roughly every ~10ms between
  frames. If the numbers look nothing like that (e.g. everything near 0, or
  wildly inconsistent), the tap point, wiring, or ground reference is wrong
  — don't trust the decoded columns until the raw numbers look sane.
- `ON/IO/PLUS/MINUS` are the decoded button states from the pazi88 logic.
  `CONFIRMED CHANGE` prints once a decoded state has repeated for 2
  consecutive frames (debounce against a single corrupted read).
- If PLUS/MINUS never trip while you're clearly pressing RES/SET, the bit
  threshold (`kBitThresholdUs = 250`) may need nudging based on what the raw
  widths actually show on your car — edit and reflash.

Once this confirms clean, consistent decodes for the buttons you care about,
that's your green light to design the real input stage into a PCB.

## Slave Display menu test (no master hardware needed)

This rig also broadcasts decoded button state to the AirLift V2 Slave
Display over ESP-NOW (`AirLiftButtons` — same struct the real master will
eventually send from `PlatformIO/src/espnow_tx.cpp`), so you can exercise
the display's on-screen menu (see `SlaveDisplay/README.md` → "MFL menu")
before wiring the actual AirLift controller.

- The channel is fixed at boot (`kEspNowChannel`, default `1`) — it must
  match the display's `ESPNOW_WIFI_CHANNEL` build flag or the menu will just
  never respond, with no other symptom.
- Only exactly-one-button decodes are ever sent (same rule
  `PlatformIO/src/mfl.cpp` applies) — an ambiguous/corrupted frame is
  broadcast as idle rather than as two buttons held at once. The raw
  `ON=/IO=/PLUS=/MINUS=` debug line printed here is unfiltered, so it can
  still show you a corrupted read even when nothing goes out over ESP-NOW
  for it.
- With no display listening, this all still runs — `esp_now_send()` failures
  aren't checked, so nothing here will complain, it just no-ops.
- The Slave Display never talks back for a menu preset-select in this setup
  (that needs the real master to receive `AirLiftCommand`) — you can drive
  the menu and watch it navigate, but "select preset" won't do anything
  downstream yet.

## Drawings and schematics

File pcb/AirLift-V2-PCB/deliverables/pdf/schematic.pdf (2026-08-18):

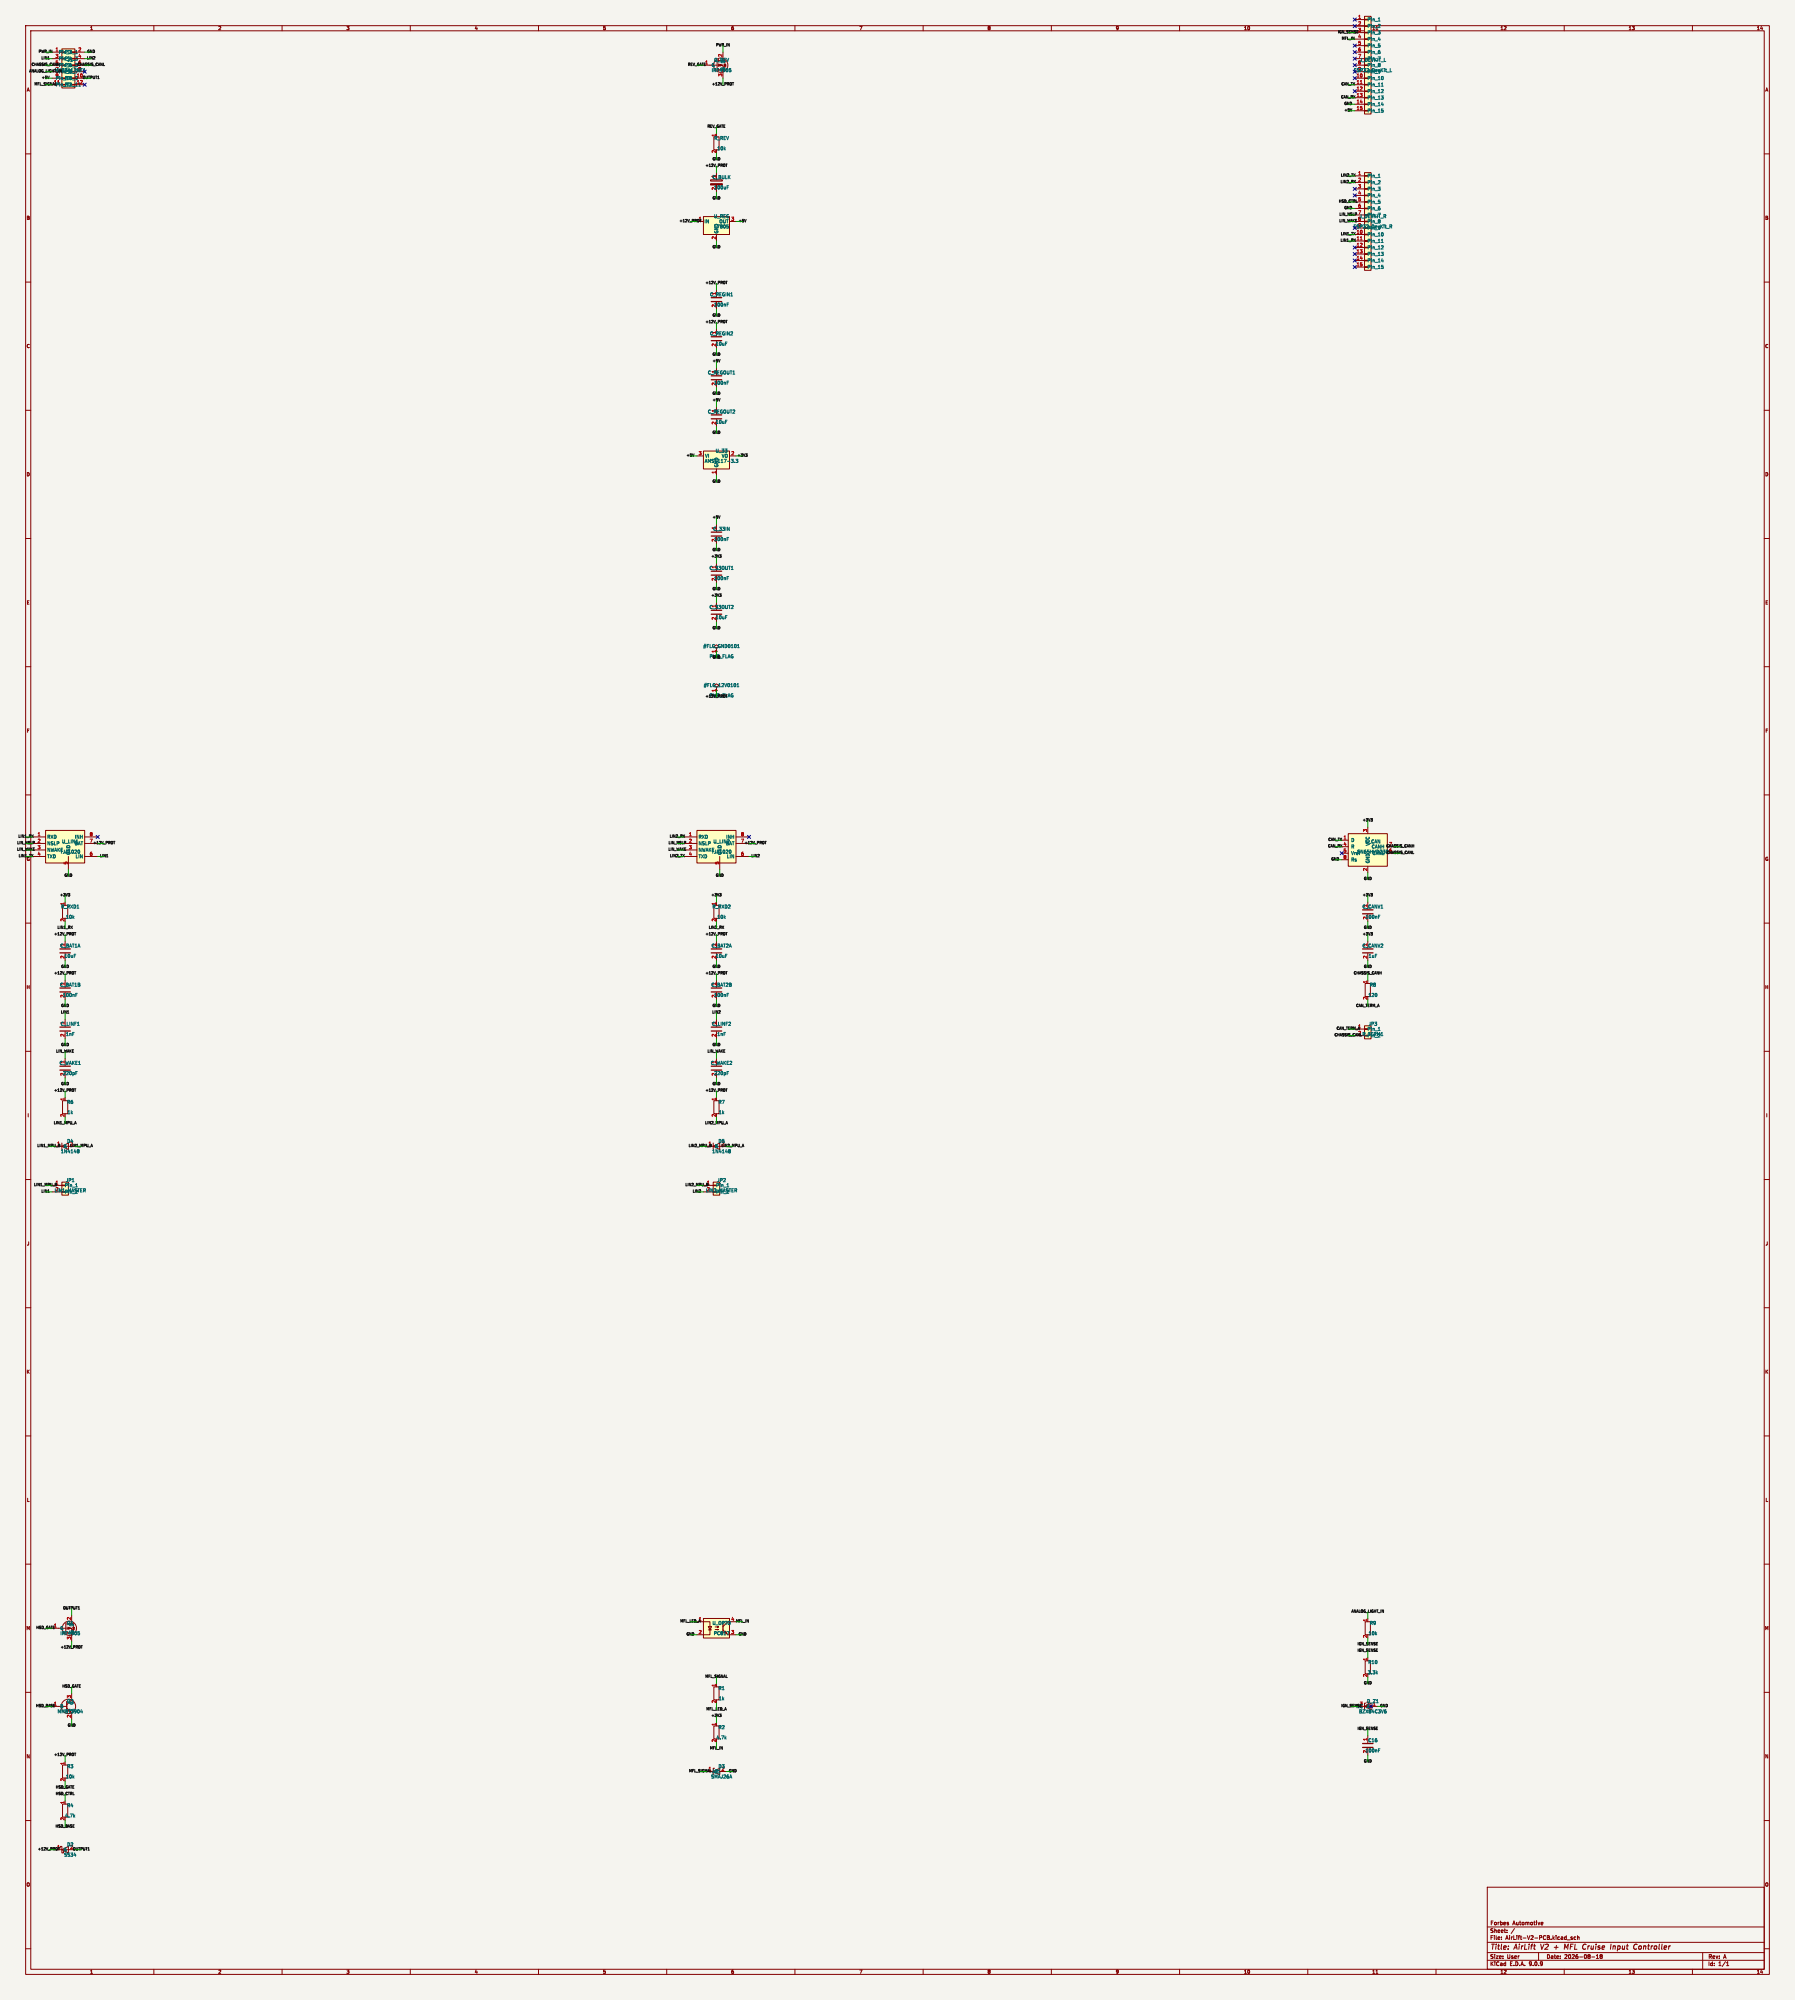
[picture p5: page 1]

J_DEVKIT_L ESP32_DevKit_L 1 2 R8
+12V_PROT GND GND GND GND

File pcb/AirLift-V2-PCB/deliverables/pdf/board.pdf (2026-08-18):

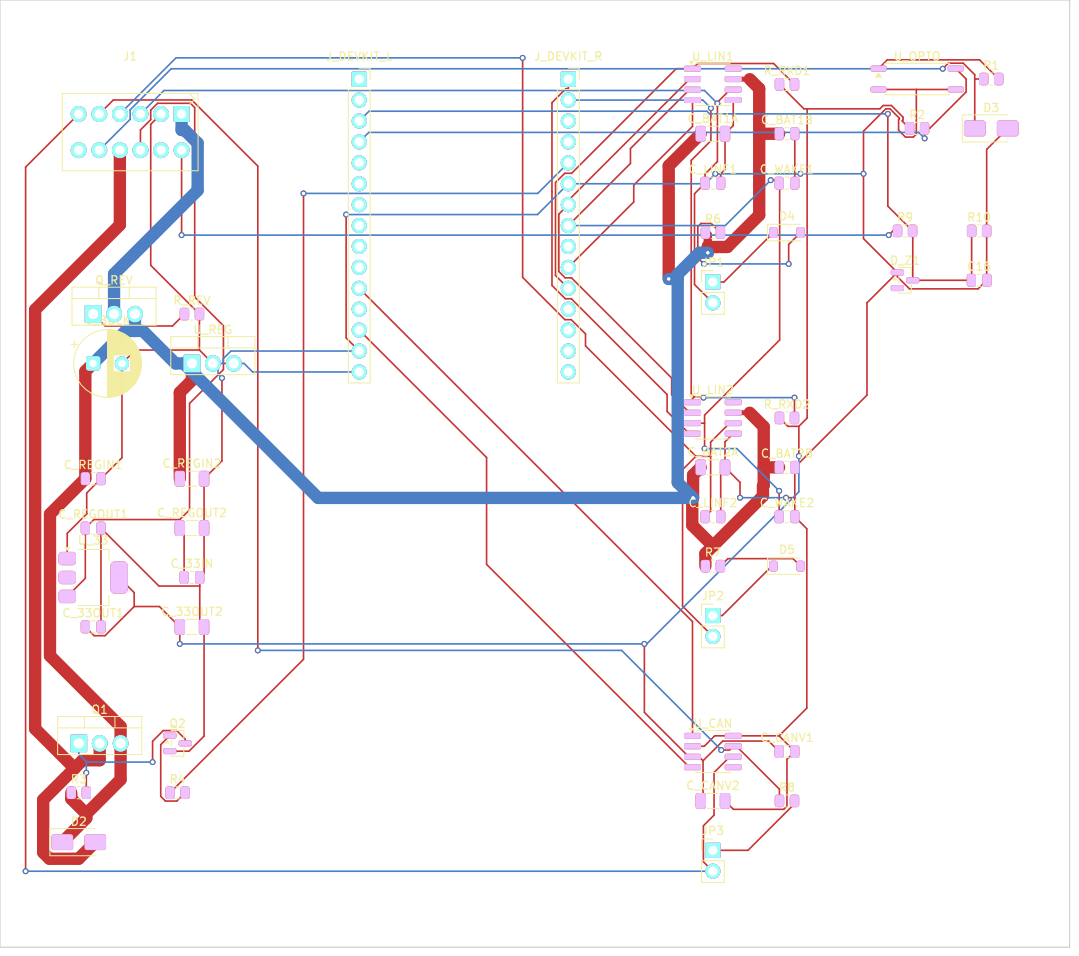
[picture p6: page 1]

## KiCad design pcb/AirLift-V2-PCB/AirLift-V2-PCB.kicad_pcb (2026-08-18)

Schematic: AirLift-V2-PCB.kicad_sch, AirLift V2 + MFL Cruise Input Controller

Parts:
C16: 100nF; C_0805_2012Metric
C_33IN, C_33OUT1: 100nF; C_0805_2012Metric
C_33OUT2: 10uF; C_1206_3216Metric
C_BAT1A, C_BAT2A: 10uF; C_1206_3216Metric
C_BAT1B, C_BAT2B: 100nF; C_0805_2012Metric
C_BULK: 100uF; CP_Radial_D8.0mm_P3.50mm
C_CANV1: 100nF; C_0805_2012Metric
C_CANV2: 1uF; C_1206_3216Metric
C_LINF1, C_LINF2: 1nF; C_0805_2012Metric
C_REGIN1: 100nF; C_0805_2012Metric
C_REGIN2: 10uF; C_1206_3216Metric
C_REGOUT1: 100nF; C_0805_2012Metric
C_REGOUT2: 10uF; C_1206_3216Metric
C_WAKE1, C_WAKE2: 220pF; C_0805_2012Metric
D2: SS34; D_SMA
D3: SMAJ26A; D_SMA
D4, D5: 1N4148; D_SOD-123
D_Z1: BZX84C3V6; SOT-23
J1: MX23A12NF1; MX23A12NF1_2x6_P2.50mm_RA
JP1: LIN1_MASTER; PinHeader_1x02_P2.54mm_Vertical
JP2: LIN2_MASTER; PinHeader_1x02_P2.54mm_Vertical
JP3: R_TERM1; PinHeader_1x02_P2.54mm_Vertical
J_DEVKIT_L: ESP32_DevKit_L; PinSocket_1x15_P2.54mm_Vertical
J_DEVKIT_R: ESP32_DevKit_R; PinSocket_1x15_P2.54mm_Vertical
Q1: IRF4905; TO-220-3_Vertical
Q2: MMBT3904; SOT-23
Q_REV: IRF4905; TO-220-3_Vertical
R1, R6, R7: 1k; R_0805_2012Metric
R2, R4: 4.7k; R_0805_2012Metric
R3, R9: 10k; R_0805_2012Metric
R8: 120; R_0805_2012Metric
R10: 3.3k; R_0805_2012Metric
R_REV: 10k; R_0805_2012Metric
R_RXD1, R_RXD2: 10k; R_0805_2012Metric
U_33: AMS1117-3.3; SOT-223-3_TabPin2
U_CAN: SN65HVD230; SOIC-8_3.9x4.9mm_P1.27mm
U_LIN1, U_LIN2: TJA1020; SOIC-8_3.9x4.9mm_P1.27mm
U_OPTO: PC817; SO-4_7.6x3.6mm_P2.54mm
U_REG: L7805; TO-220-3_Vertical

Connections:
+3V3: C_33OUT1.1, C_33OUT2.1, C_CANV1.1, C_CANV2.1, R2.1, R_RXD1.1, R_RXD2.1, U_33.2 (VO), U_CAN.3 (VCC)
+5V: C_33IN.1, C_REGOUT1.1, C_REGOUT2.1, J1.9, J_DEVKIT_L.15, U_33.3 (VI), U_REG.3 (OUT)
+12V_PROT: C_BAT1A.1, C_BAT1B.1, C_BAT2A.1, C_BAT2B.1, C_BULK.1, C_REGIN1.1, C_REGIN2.1, D2.1 (K), Q1.3 (S), Q_REV.3 (S), R3.1, R6.1, R7.1, U_LIN1.7 (BAT), U_LIN2.7 (BAT), U_REG.1 (IN)
ANALOG_LIGHT_IN: J1.7, R9.1
CAN_RX: J_DEVKIT_L.13, U_CAN.4 (R)
CAN_TERM_A: JP3.1, R8.2
CAN_TX: J_DEVKIT_L.11, U_CAN.1 (D)
CHASSIS_CANH: J1.5, R8.1, U_CAN.7 (CANH)
CHASSIS_CANL: J1.6, JP3.2, U_CAN.6 (CANL)
GND: C16.2, C_33IN.2, C_33OUT1.2, C_33OUT2.2, C_BAT1A.2, C_BAT1B.2, C_BAT2A.2, C_BAT2B.2, C_BULK.2, C_CANV1.2, C_CANV2.2, C_LINF1.2, C_LINF2.2, C_REGIN1.2, C_REGIN2.2, C_REGOUT1.2, C_REGOUT2.2, C_WAKE1.2, C_WAKE2.2, D3.2 (A2), D_Z1.1 (A), J1.2, J_DEVKIT_L.14, J_DEVKIT_R.6, Q2.2 (E), R10.2, R_REV.2, U_33.1 (GND), U_CAN.2 (GND), U_CAN.8 (Rs), U_LIN1.5 (GND), U_LIN2.5 (GND), U_OPTO.2, U_OPTO.3, U_REG.2 (GND)
HSD_BASE: Q2.1 (B), R4.2
HSD_CTRL: J_DEVKIT_R.5, R4.1
HSD_GATE: Q1.1 (G), Q2.3 (C), R3.2
IGN_SENSE: C16.1, D_Z1.3 (K), J_DEVKIT_L.3, R9.2, R10.1
LIN1: C_LINF1.1, J1.3, JP1.2, U_LIN1.6 (LIN)
LIN1_MPU_A: D4.2 (A), R6.2
LIN1_MPU_B: D4.1 (K), JP1.1
LIN1_RX: J_DEVKIT_R.11, R_RXD1.2, U_LIN1.1 (RXD)
LIN1_TX: J_DEVKIT_R.10, U_LIN1.4 (TXD)
LIN2: C_LINF2.1, J1.4, JP2.2, U_LIN2.6 (LIN)
LIN2_MPU_A: D5.2 (A), R7.2
LIN2_MPU_B: D5.1 (K), JP2.1
LIN2_RX: J_DEVKIT_R.2, R_RXD2.2, U_LIN2.1 (RXD)
LIN2_TX: J_DEVKIT_R.1, U_LIN2.4 (TXD)
LIN_NSLP: J_DEVKIT_R.7, U_LIN1.2 (NSLP), U_LIN2.2 (NSLP)
LIN_WAKE: C_WAKE1.1, C_WAKE2.1, J_DEVKIT_R.8, U_LIN1.3 (NWAKE), U_LIN2.3 (NWAKE)
MFL_IN: J_DEVKIT_L.4, R2.2, U_OPTO.4
MFL_LED_A: R1.2, U_OPTO.1
MFL_SIGNAL: D3.1 (A1), J1.11, R1.1
OUTPUT1: D2.2 (A), J1.10, Q1.2 (D)
PWR_IN: J1.1, Q_REV.2 (D)
REV_GATE: Q_REV.1 (G), R_REV.1

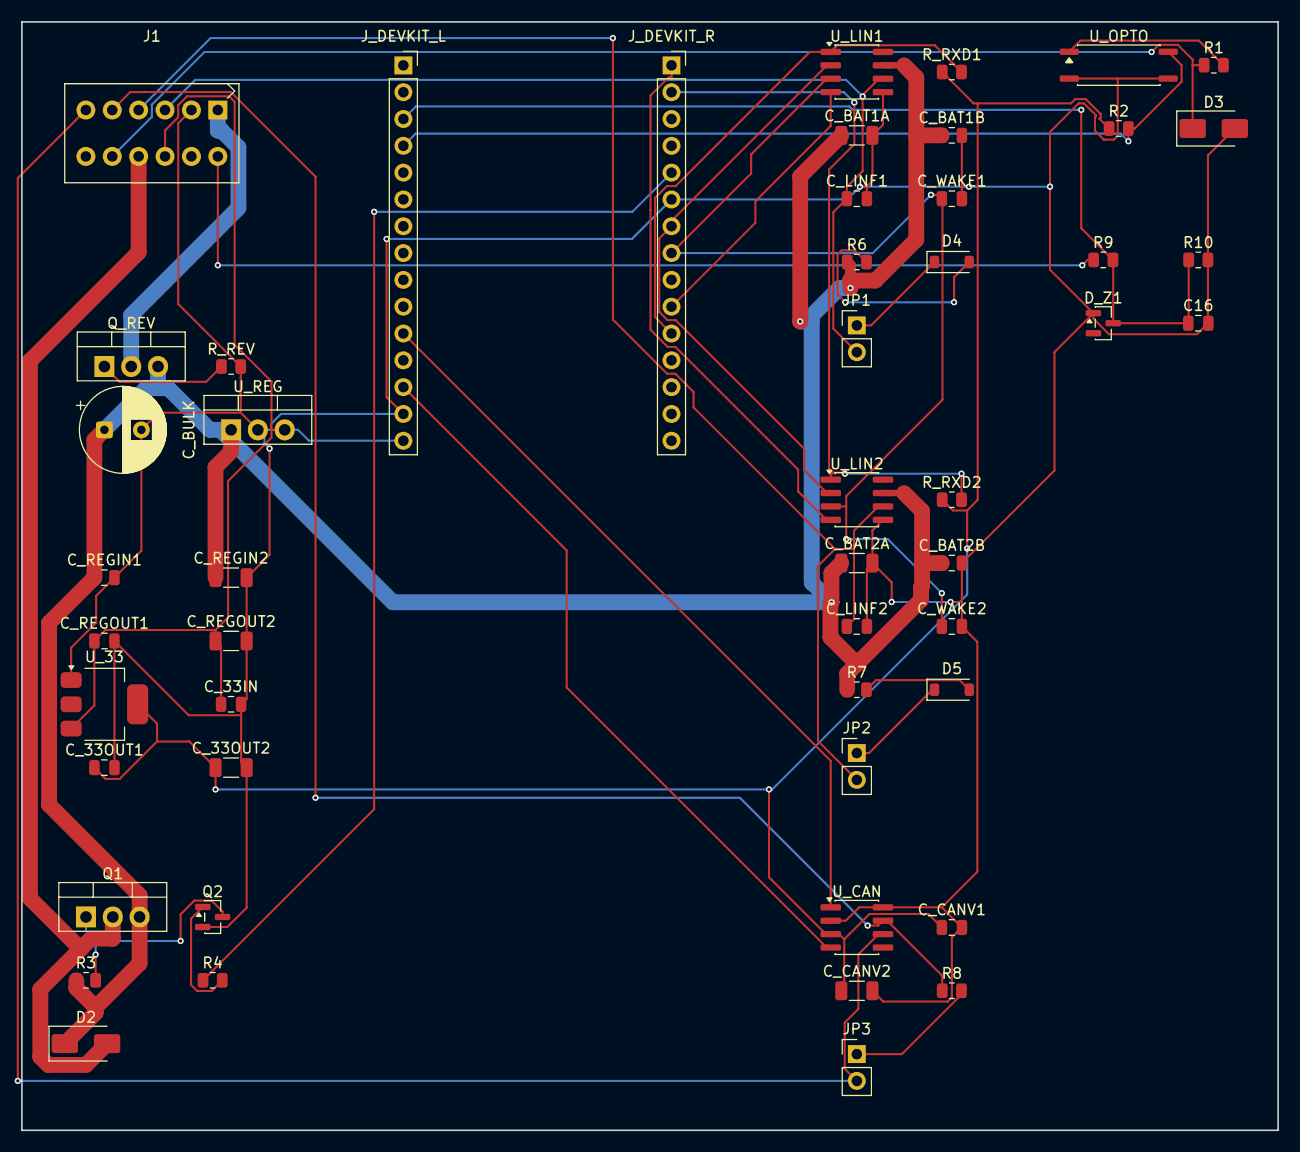
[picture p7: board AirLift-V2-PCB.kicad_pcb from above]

Board: 2 copper layers, 119.0 x 105.0 mm, 51 parts (0 on the bottom side), 32 nets.

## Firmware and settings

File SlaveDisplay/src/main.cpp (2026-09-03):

// ---------------------------------------------------------------------------
// AirLift V2 — Slave Display
//
// ESP32-2432S028R (Cheap Yellow Display). Listens for AirLiftData broadcasts
// from the AirLift V2 MITM master over ESP-NOW and renders them as a four
// corner pressure cluster with tank / preset / status readouts.
//
// This end is receive-only: it never transmits, never pairs, and holds no
// state of its own beyond "what did the last packet say".
// ---------------------------------------------------------------------------
#include <Arduino.h>

#include "airlift_espnow.h"
#include "config.h"
#include "display.h"
#include "espnow_link.h"
#include "menu.h"
#include "touch.h"

namespace {

// Last packet contents. Held (dimmed) on screen when the link drops so the
// driver can still see where the car was parked.
AirLiftData data = {};

#if DEMO_MODE
// Bench test without a master. Ticks at the rate the master will actually send
// at, not at loop() speed, so the panel looks like the real thing — and sweeps
// the corners across the whole 0..160 psi range so the widest value the display
// can ever show gets exercised on glass.
#define DEMO_TICK_MS 150

void demoTick() {
  const float t = millis() / 1000.0f;
  data.fl     = 80.0f + 80.0f * sinf(t * 0.25f);
  data.fr     = 80.0f + 80.0f * sinf(t * 0.25f + 0.3f);
  data.rl     = 80.0f + 80.0f * sinf(t * 0.20f + 1.1f);
  data.rr     = 80.0f + 80.0f * sinf(t * 0.20f + 1.4f);
  data.tank   = 140.0f + 20.0f * sinf(t * 0.2f);
  data.preset = 1 + ((uint8_t)(t / 5.0f) % 8);
  data.status = (uint8_t)(((uint32_t)t / 3) % 3);
}
#endif

// Preset display names, synced from the master over ESP-NOW (AirLiftPresetNames
// -- see espnow_link.h/kEspNowPresetNamesPeriodMs on the master). These
// defaults are what's shown until the first packet arrives after boot (or if
// the master is running old firmware that never sends one); they are not
// necessarily what the master actually has configured.
char presetNamesBuf[8][24] = {
  "SLAM", "DRIVE", "SPORT", "PRESET 4",
  "PRESET 5", "PRESET 6", "PRESET 7", "PRESET 8",
};

}  // namespace

const char* presetName(uint8_t preset) {
  if (preset < 1 || preset > 8) return "---";
  return presetNamesBuf[preset - 1];
}

void setup() {
  Serial.begin(SERIAL_BAUD);
  delay(200);
  Serial.println("\n[SYS] AirLift V2 slave display booting");

  // Loads persisted settings (ROTATE 180) from NVS -- must run before
  // display::begin() so each board's initial panel rotation is already known
  // at init time rather than only taking effect the next time the menu is
  // opened.
  menu::begin();

  display::begin();

  // Bring the radio up before the splash blocks: packets that arrive during
  // those two seconds then count, so the gauge can come up already live
  // instead of sitting on NO SIGNAL while the master is plainly talking.
  espnow::begin();
  touch::begin();

  display::splash();
  display::drawStaticLayout();

  // Whatever arrived during the splash, or NO SIGNAL if nothing did.
  espnow::take(data);
  display::update(data, espnow::alive());
  Serial.println("[SYS] ready");
}

void loop() {
  // Menu state comes from the master's MFL button broadcast regardless of
  // DEMO_MODE (that flag only fakes pressure telemetry).
  menu::poll();

  // Preset names sync independently of DEMO_MODE/telemetry, same reasoning
  // as menu::poll() above -- a real master nearby should still correct the
  // placeholder names even while bench-testing fake pressures.
  {
    AirLiftPresetNames pn;
    if (espnow::takePresetNames(pn)) {
      memcpy(presetNamesBuf, pn.names, sizeof(presetNamesBuf));
      // The wire format is NUL-padded, not guaranteed NUL-terminated (a name
      // that fills all 24 bytes) -- force it so presetName()'s callers can
      // keep treating this as a plain C string.
      for (auto& name : presetNamesBuf) name[sizeof(name) - 1] = '\0';
    }
  }

  // Telemetry ingestion runs unconditionally, whether or not the menu is
  // open — the MANUAL_ACTIVE screen shows live pressures while you hold
  // PLUS/MINUS, which needs `data` to actually keep updating in the
  // background rather than freezing at whatever it was when the menu opened.
#if DEMO_MODE
  static uint32_t nextTick = 0;
  bool gotFreshData = false;
  if ((int32_t)(millis() - nextTick) >= 0) {
    nextTick = millis() + DEMO_TICK_MS;
    demoTick();
    gotFreshData = true;
  }
#else
  const bool gotFreshData = espnow::take(data);
  if (gotFreshData) {
    Serial.printf("[NOW] FL %.1f FR %.1f RL %.1f RR %.1f tank %.1f "
                  "preset %u status %u\n",
                  data.fl, data.fr, data.rl, data.rr, data.tank,
                  data.preset, data.status);
  }
#endif

  // A GAUGE<->MENU transition means the screen currently holds pixels from
  // whichever mode isn't running any more — force the entered mode to
  // repaint everything rather than trust either side's diff cache.
  static bool wasMenuActive = false;
  const bool  menuActive    = menu::active();
  if (menuActive != wasMenuActive) {
    if (menuActive) {
      display::drawMenu(menu::currentView(data), true);
    } else {
      display::drawStaticLayout();   // also resets update()'s diff cache
    }
    wasMenuActive = menuActive;
  }

  if (menuActive) {
    display::drawMenu(menu::currentView(data), false);
  } else {
    // update() diffs internally, so calling it every pass is cheap — it only
    // touches the panel when a rendered value actually changed (including
    // the link going stale).
#if DEMO_MODE
    if (gotFreshData) display::update(data, true);
#else
    display::update(data, espnow::alive());
#endif
  }

  touch::poll();
  delay(10);
}

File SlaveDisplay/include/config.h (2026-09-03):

#pragma once

#include <Arduino.h>

// ---------------------------------------------------------------------------
// Five boards (nine envs -- cyd, round128, round21, and lcd147 each have two
// rendering-backend variants) share this firmware:
//
//   - ESP32-2432S028R "Cheap Yellow Display" (default) — ILI9341 320x240
//     landscape + XPT2046 resistive touch on its own SPI bus. Two rendering
//     backends: env:cyd (raw TFT_eSPI draw calls — src/display.cpp, shared
//     with round128/lcd147) and env:cyd_lvgl (LVGL — src/display_cyd_lvgl.cpp,
//     include/lv_conf.h), both using src/touch.cpp unchanged.
//   - Waveshare ESP32-S3-LCD-1.28 (build flag DISPLAY_ROUND=1) — plain,
//     non-touch, CNC metal case variant. GC9A01 240x240 round panel, no
//     touch hardware on this unit (CST816T support stays compiled in behind
//     ENABLE_TOUCH=0 for boards that do have it). Two rendering backends:
//     env:round128 (raw TFT_eSPI draw calls — src/display.cpp, shared with
//     cyd/lcd147) and env:round128_lvgl (LVGL —
//     src/display_round128_lvgl.cpp, include/lv_conf.h), both using
//     src/touch.cpp (ENABLE_TOUCH=0 stub) unchanged.
//   - Waveshare ESP32-S3-Touch-LCD-2.1 (build flag BOARD_ROUND21=1) —
//     ST7701 480x480 round panel driven over the ESP32-S3's RGB-parallel LCD
//     peripheral (not SPI), reset/CS/power gated through a TCA9554 I2C IO
//     expander, CST820 capacitive touch on I2C. TFT_eSPI has no working
//     ST7701-RGB support. Panel bring-up (src/panel_round21.cpp) is shared
//     by two rendering backends: env:round21 (Arduino_GFX --
//     src/display_round21.cpp) and env:round21_lvgl (LVGL --
//     src/display_round21_lvgl.cpp, include/lv_conf.h), both using
//     src/touch_round21.cpp and src/tca9554.cpp unchanged.
//   - Generic ESP32-S3 devkit + 1.3" SH1106 128x64 monochrome OLED, I2C
//     (build flag BOARD_OLED13=1) — the intended production screen size.
//     Adafruit_SH110X, own implementation: src/display_oled13.cpp,
//     src/touch_oled13.cpp (this board has no touch hardware at all, so
//     that file is just a stub). No backlight — "brightness" maps to the
//     SH1106's contrast register instead of PWM.
//   - Waveshare ESP32-S3-LCD-1.47B (build flag BOARD_LCD147=1) — ST7789
//     172x320 SPI panel, rotated to a 320x172 landscape canvas, no touch
//     hardware. Two rendering backends, both using this board's ST7789
//     TFT_eSPI config as-is (unlike round21, TFT_eSPI already has working
//     support for this panel, so there was no reason to bypass it for the
//     LVGL backend): env:lcd147 (raw TFT_eSPI draw calls --
//     src/display.cpp, shared with cyd/round128) and env:lcd147_lvgl (LVGL
//     -- src/display_lcd147_lvgl.cpp, include/lv_conf.h). src/touch.cpp
//     (ENABLE_TOUCH=0 makes it compile to a no-op stub) is shared unchanged
//     by both.
//
// platformio.ini's build_src_filter keeps each env compiling only its own
// display/touch files. Panel SPI pins for the two TFT_eSPI boards live in
// platformio.ini as TFT_eSPI build flags. Everything else board-specific —
// touch pins, panel pins/timing, I2C pins, and layout geometry — lives here.
// ---------------------------------------------------------------------------

#if defined(DISPLAY_ROUND)

// --- Touch (CST816T, I2C, shared bus with the onboard QMI8658 IMU) ---------
// Pins per TFT_eSPI's bundled Setup302_Waveshare_ESP32S3_GC9A01.h (panel) and
// a community-verified PlatformIO build for this exact board (touch) —
// re-check against your unit's silkscreen/schematic before relying on it;
// Waveshare sells several similarly-named 1.28" variants (plain LCD-1.28 has
// no touch at all, DualEye-1.28 is a different board) with different pinouts.
#define TOUCH_SDA 6
#define TOUCH_SCL 7
#define TOUCH_RST 13
#define TOUCH_IRQ 5

// Ignore repeat taps inside this window.
#define TP_DEBOUNCE_MS 250

#elif defined(BOARD_ROUND21)

// --- I2C bus (TCA9554 IO expander + CST820 touch share this bus) -----------
// Pins and everything below per Waveshare's own Arduino demo for this board
// (Display_ST7701 / TCA9554PWR / Touch_CST820 / I2C_Driver) — re-verify
// against your unit if you have a different revision.
#define I2C_SDA_PIN 15
#define I2C_SCL_PIN 7

// --- ST7701 panel: init is 3-wire-SPI-style register writes (no MISO, CS
// held by the IO expander, not a real CS pin), then the ESP32-S3's RGB LCD
// peripheral drives actual pixel data. -------------------------------------
#define LCD_SPI_CLK_PIN  2
#define LCD_SPI_MOSI_PIN 1
#define LCD_BACKLIGHT_PIN 6

#define RGB_PCLK_PIN  41
#define RGB_HSYNC_PIN 38
#define RGB_VSYNC_PIN 39
#define RGB_DE_PIN    40
// B0..B4, G0..G5, R0..R4 — order the ESP-IDF RGB panel driver expects.
#define RGB_DATA_PINS {5, 45, 48, 47, 21, 14, 13, 12, 11, 10, 9, 46, 3, 8, 18, 17}
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

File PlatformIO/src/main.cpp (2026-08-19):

#include <Arduino.h>

#include "API.h"
#include "CAN.h"
#include "defs.h"
#include "espnow_tx.h"
#include "io.h"
#include "mfl.h"
#include "power_manager.h"
#include "SavvyCAN.h"
#include "tasks.h"

void setup() {
  basicInit();
  canInit();
  mflInit();
  setupWiFi();
  setupApiServer();
  // ESP-NOW rides the soft-AP's radio, so it can only start once WiFi is up.
  espnowTxInit();
  savvyCanInit();

  // Universal reduced-power module: turns WiFi off after the last web client
  // disconnects, scales the CPU 240->80 MHz, releases Bluetooth and kills the
  // onboard LED to cut current draw (and therefore linear-regulator heat).
  // Reconnecting a client (or an ignition power-cycle) brings WiFi back.
  power_config_t pcfg = powerDefaultConfig();
  // The module prints its own [PWR] lines; route them through the master gate
  // so a single enableDebug (and debugPower) controls them too.
  pcfg.verbose = (enableDebug && debugPower);
  powerInit(&pcfg);

  startTasks();
}

void loop() {
  vTaskDelay(pdMS_TO_TICKS(1000));
}

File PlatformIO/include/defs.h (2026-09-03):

#pragma once

#include <Arduino.h>

#include "airlift_ver.h"   // FW_VERSION (single source of truth; shown in the UI)

// ---------------------------------------------------------------------------
// Serial debug
//
//   * enableDebug is the SINGLE control point. Set it to 0 to turn off every
//     serial debug statement.
//   * With enableDebug = 1, set the flags below to choose specific Serial outputs
// ---------------------------------------------------------------------------
#define enableDebug 1        // ** MASTER ** 0 = silence ALL serial debug

#define debugSys    1        // [SYS]   boot / general / 1 Hz telemetry
#define debugPower  1        // [PWR]   power_manager (reduced power / wake)
#define debugWifi   1        // [WiFi]  soft-AP + web server bring-up
#define debugIO     1        // [IO]    high-side / controller power / UART init
#define debugCAN    1        // [CAN]   TWAI driver + vehicle CAN / fob
#define debugLIN    1        // [LIN]   AirLift LIN MITM (wire / mode / buttons)
#define debugAPI    1        // [API]   REST / settings / OTA
#define debugSavvy  1        // [SAVVY] SavvyCAN GVRET bridge
#define debugMFL    1        // [MFL]   steering-wheel cruise-button decode

#define serialDebugBaud 115200

// --- Master / general (uncategorised) ---
#if enableDebug && debugSys
#define DEBUG(x, ...)  Serial.printf("[SYS] " x "\r\n", ##__VA_ARGS__)
#define DEBUG_(x, ...) Serial.printf("[SYS] " x, ##__VA_ARGS__)
#else
#define DEBUG(x, ...)
#define DEBUG_(x, ...)
#endif

// --- [PWR] power management ---
#if enableDebug && debugPower
#define DEBUG_PWR(x, ...)  Serial.printf("[PWR] " x "\r\n", ##__VA_ARGS__)
#define DEBUG_PWR_(x, ...) Serial.printf("[PWR] " x, ##__VA_ARGS__)
#else
#define DEBUG_PWR(x, ...)
#define DEBUG_PWR_(x, ...)
#endif

// --- [WiFi] soft-AP + web server ---
#if enableDebug && debugWifi
#define DEBUG_WIFI(x, ...)  Serial.printf("[WiFi] " x "\r\n", ##__VA_ARGS__)
#define DEBUG_WIFI_(x, ...) Serial.printf("[WiFi] " x, ##__VA_ARGS__)
#else
#define DEBUG_WIFI(x, ...)
#define DEBUG_WIFI_(x, ...)
#endif

// --- [IO] high-side / controller power / UART init ---
#if enableDebug && debugIO
#define DEBUG_IO(x, ...)  Serial.printf("[IO] " x "\r\n", ##__VA_ARGS__)
#define DEBUG_IO_(x, ...) Serial.printf("[IO] " x, ##__VA_ARGS__)
#else
#define DEBUG_IO(x, ...)
#define DEBUG_IO_(x, ...)
#endif

// --- [CAN] TWAI driver + vehicle CAN ---
#if enableDebug && debugCAN
#define DEBUG_CAN(x, ...)  Serial.printf("[CAN] " x "\r\n", ##__VA_ARGS__)
#define DEBUG_CAN_(x, ...) Serial.printf("[CAN] " x, ##__VA_ARGS__)
#else
#define DEBUG_CAN(x, ...)
#define DEBUG_CAN_(x, ...)
#endif

// --- [LIN] AirLift MITM (wire / mode / buttons) ---
#if enableDebug && debugLIN
#define DEBUG_LIN(x, ...)  Serial.printf("[LIN] " x "\r\n", ##__VA_ARGS__)
#define DEBUG_LIN_(x, ...) Serial.printf("[LIN] " x, ##__VA_ARGS__)
#else
#define DEBUG_LIN(x, ...)
#define DEBUG_LIN_(x, ...)
#endif

// --- [API] REST / settings / OTA ---
#if enableDebug && debugAPI
#define DEBUG_API(x, ...)  Serial.printf("[API] " x "\r\n", ##__VA_ARGS__)
#define DEBUG_API_(x, ...) Serial.printf("[API] " x, ##__VA_ARGS__)
#else
#define DEBUG_API(x, ...)
#define DEBUG_API_(x, ...)
#endif

// --- [SAVVY] SavvyCAN GVRET bridge ---
#if enableDebug && debugSavvy
#define DEBUG_SAVVY(x, ...)  Serial.printf("[SAVVY] " x "\r\n", ##__VA_ARGS__)
#define DEBUG_SAVVY_(x, ...) Serial.printf("[SAVVY] " x, ##__VA_ARGS__)
#else
#define DEBUG_SAVVY(x, ...)
#define DEBUG_SAVVY_(x, ...)
#endif

// --- [MFL] steering-wheel cruise-button decode ---
#if enableDebug && debugMFL
#define DEBUG_MFL(x, ...)  Serial.printf("[MFL] " x "\r\n", ##__VA_ARGS__)
#define DEBUG_MFL_(x, ...) Serial.printf("[MFL] " x, ##__VA_ARGS__)
#else
#define DEBUG_MFL(x, ...)
#define DEBUG_MFL_(x, ...)
#endif

// ---------------------------------------------------------------------------
// Pin assignments — MQB Steering Wheel Controller PCB
// On-wire data is 9600-baud 8N1 UART via LIN transceivers.
// ---------------------------------------------------------------------------
// Controller side — UART1.
// The Controller is the *bus master*: when it is unplugged the
// LIN channel is completely silent (proven by the "controller disconnected" capture).

constexpr int pinTX_Controller = 17;
constexpr int pinRX_Controller = 16;

// MANIFOLD side — UART2.
constexpr int pinTX_Manifold   = 23;
constexpr int pinRX_Manifold   = 22;

// Global Wake and Chip-Select pins for the LIN transceivers
constexpr int pinWake_LIN = 18;   // WAKE on TJA1020 — held HIGH for normal operation (same as MFSW controller)
constexpr int pinCS_LIN   = 19;   // HIGH = enable transceivers (chip select / power enable)

// CAN bus pins (ESP32 TWAI driver)
constexpr int pinCAN_RX = 13;
constexpr int pinCAN_TX = 14;

// High-side MOSFET (5A) to power the controller
constexpr int pinControllerPower = 21;   // HIGH = keep +12 V to handheld during air-out (ignition off)
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

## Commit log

2026-08-17 Add PCB requirements for MFL cruise-button input
    Documents combining the existing AirLift V2 board (LIN/CAN/ignition/
    high-side driver) with a new isolated input for BMW MFL steering-wheel
    cruise buttons, validated on a bench prototype in test/mfl_sniffer.
2026-08-17 Add MFL cruise-button bench sniffer
    Standalone ESP32/PlatformIO rig (not part of the AirLift firmware) that
    decodes the BMW MFL cruise-control single-wire PWM protocol through a
    4N35 optocoupler isolation stage. Used to validate the signal on a real
    car before committing to the PCB design in pcb/PCB-REQUIREMENTS.md.
2026-08-18 Fix MFL idle decode, add stepper sweep test and findings doc
    - main.cpp: treat value==0 as idle instead of decoding it as all
    four buttons pressed simultaneously
    - add standalone stepper_sweep bench test for the 28BYJ-48/ULN2003AN
    - add MFL-FINDINGS.md summarizing the cruise-button protocol work
    - ignore .DS_Store
    [main.cpp]
2026-08-18 V2.11: ESP-NOW broadcast to slave cluster display
    Adds a one-way ~10 Hz broadcast of the 24-byte AirLiftData packet
    (airlift_espnow.h) to FF:FF:FF:FF:FF:FF, and the CYD cluster display
    that receives it in SlaveDisplay/. Broadcast means no pairing and no
    knowledge of the display's MAC.
    Firmware:
    * espnow_tx.cpp sends four corners, tank, active preset and
    idle/raising/lowering state. The wire carries neither of the last
    two directly, so preset is matched back from the 01 16 47 target
    pressures against the preset table, and direction comes from a
    held button or the corner-pressure trend.
    * Soft-AP channel pinned to kEspNowChannel so it matches the fixed
    channel the display parks on;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
    [app.js, config.h, defs.h]
2026-08-18 Add AirLift V2 + MFL controller PCB design
    KiCad project for the controller board built from the PCB requirements:
    schematic, layout, custom symbol/footprint library, and fab deliverables
    (gerbers, drill, BOM, pick-and-place, PDFs).
    ~130 x 115 mm, ERC and DRC clean with only cosmetic silkscreen warnings.
    High-current nets (PWR_IN, +12V_PROT, OUTPUT1, up to 5A) route on a
    dedicated 1.5mm Power5A netclass. See DESIGN-NOTES.md for judgment calls
    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
    [AirLift-V2-PCB-B_Courtyard.gbr, AirLift-V2-PCB-B_Cu.gbl, AirLift-V2-PCB-B_Fab.gbr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]
2026-08-19 Add round-panel Slave Display ports: Waveshare 1.28 and 2.1
    round128 (GC9A01 240x240 + CST816T) shares display.cpp/touch.cpp with the
    CYD, driven entirely by geometry/pins in config.h.
    round21 (Waveshare ESP32-S3-Touch-LCD-2.1, ST7701 480x480 RGB-parallel +
    CST820, TCA9554 IO expander) can't share those files since TFT_eSPI has no
    working ST7701-RGB support, so it gets its own Arduino_GFX-based
    display_round21.cpp/touch_round21.cpp/tca9554.cpp behind the same
    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
2026-08-19 Port MFL cruise-button decode to the master, make ESP-NOW bidirectional
    MFL-FINDINGS.md's own next-steps listed this as pending: mfl.cpp/.h ports
    the bench sniffer's ISR-driven pulse-train decoder onto GPIO34 (the
    production PCB pin, confirmed on the fabricated board's net list), applying
    the same exactly-one-button validity rule documented there.
    ESP-NOW gains two new packet types alongside the existing AirLiftData
    telemetry (airlift_espnow.h): AirLiftButtons (master->slave, ~20 Hz, live
    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
2026-08-19 Add MFL-driven on-screen menu to the Slave Display (cyd/round128/round21)
    Receives the master's new AirLiftButtons broadcast and derives button-press
    edges itself (state, not events, so a dropped broadcast just gets caught up
    by the next one instead of losing a press). New board-agnostic menu.cpp
    owns the state machine — Presets (select one, sends AirLiftCommand back to
    the master) and Settings (backlight, local-only, not persisted) — driven by
    IO=enter/select, PLUS/MINUS=up/down, SET/ON=back.
    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
2026-08-19 Broadcast AirLiftButtons from the MFL bench sniffer
    Lets the Slave Display's new on-screen menu be exercised from the bench rig
    before the real AirLift master hardware is wired up. Broadcasts at ~20 Hz,
    independent of the frame-driven raw decode loop, and applies the same
    exactly-one-button validity filter the master's mfl.cpp uses (an ambiguous
    decode goes out as idle, not as multiple buttons at once) while keeping the
    existing raw ON/IO/PLUS/MINUS debug print unfiltered for diagnosing a noisy
    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
2026-08-19 Add 1.3" SH1106 OLED (oled13) — the production Slave Display size
    Fourth board env: generic ESP32-S3 devkit + 128x64 monochrome I2C OLED, no
    touch hardware (touch_oled13.cpp is an unconditional stub — every input is
    the MFL menu). Adafruit_SH110X, since it's a genuinely different rendering
    target (no colour, a fraction of the other boards' pixel budget) rather
    than a shrunk copy of their 2x2 grid:
    - Corner pressures big (size-2) on two rows, F/R axle-labelled, left/right
    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
2026-08-19 Add master-side manual-button command handling for the MFL menu
    CMD_MANUAL_PRESS/RELEASE let the slave's MANUAL screen actually drive the
    manifold: queueManualButton()/releaseManualButton() dedup the critical
    section previously duplicated between /api/intercept/manual and the new
    ESP-NOW command handler in espnow_tx.cpp. Also adds the axle-combined
    BTN_MANUAL_FRONT_*/REAR_* codes (extrapolated from the documented bit
    scheme, flagged as unverified against a real capture).
2026-08-19 Add axle-specific MANUAL control, SETTINGS extras, and burn-in protection
    MANUAL control screen (all four boards): FRONT/REAR/ALL axle selection,
    CMD_MANUAL_PRESS/RELEASE wired through espnow_link, live pressures + a
    direction indicator while a button is held (fancier per-board rendering:
    colour-coded triangle on cyd/round128/round21, filled triangle glyph on
    oled13). ALL uses the real handheld's BTN_MANUAL_ALL_UP/DOWN codes.
    SETTINGS: reordered to the end of the top menu; BACKLIGHT gained a proper
    edit submode now that the list can hold more than one item; oled13 gained
    an INVERT toggle (contrast/DC-DC pump adjustment confirmed to have no
    visible effect on that panel via a full-screen flas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
    [config.h, display.cpp, display_oled13.cpp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]
2026-08-24 Add standalone bench CAN sniffer
    Listen-only ESP32 + TJA1050/SN65HVD230 transceiver rig for confirming
    whether a bus is actually present/readable on a pair of wires before
    trusting a multimeter reading or wiring anything permanent. Prints every
    frame plus a 1s bus-status/error-counter line, never transmits or ACKs.
    [main.cpp]
2026-08-24 Add Waveshare ESP32-S3-LCD-1.47B (lcd147) board, OEM-orange colour scheme
    New env: ST7789 172x320 panel rotated to a 320x172 landscape canvas, no
    touch hardware, reusing the CYD/round128 TFT_eSPI display.cpp/touch.cpp
    as-is (ENABLE_TOUCH=0 compiles touch.cpp to a no-op stub). Two board-specific
    quirks handled in display.cpp: GPIO46 (this board's LCD_BL pin) is the
    ESP32-S3's one genuinely input-only GPIO, so setBacklight() is a no-op there
    (backlight is hardware-always-on); the onboard addressable RGB LED (GPIO38)
    gets an explicit off-write at boot since it otherwise powers up showing a
    colour.
    Also reworks the shared colour palette (config.h, applies to every TFT/GFX
    board) to an early-200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
    [config.h, display.cpp]
2026-08-24 MFL bring-up: add diagnostics, move MFL signal to GPIO39
    Real master hardware surfaced two problems that only showed up once we
    finally had it connected: the event log looked completely silent for MFL
    activity, and (per the KiCad netlist) GPIO34 -- the original PCB plan for
    MFL_IN -- was never actually wired on the fabricated board.
    mfl.cpp/mfl.h: mflDiagTick() logs raw ISR edge count, completed-frame
    count, and the last decoded raw value (before the exactly-one-match
    filter) once a second to serial and once every 5s to the persisted event
    log, so a bring-up session can distinguish "nothing reaching the GPIO"
    from "signal arriving but never syncing" from "frames decoding but never
    passing t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
    [app.js, defs.h, io.cpp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]
2026-08-24 Terminate serial debug lines with CRLF
    Every DEBUG_* macro emitted a bare "\n". In a raw serial terminal that is a
    line feed with no carriage return, so each line started where the previous
    one ended and the log walked off to the right. Serial.println() elsewhere
    emits \r\n natively, which is why only some lines drifted -- and why the
    bench sniffer, which already used \r\n explicitly, looked fine.
    powerLog() builds its own printf rather than going through the macros, so it
    had the same bug.
    The trailing-underscore variants (DEBUG_, DEBUG_PWR_, ...) are intentionally
    left alone -- they exist to build a line in pieces and must not terminate it.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
    [defs.h, power_manager.cpp]
2026-08-24 MFL: signal is not inverted on the MFSW aux input
    Fixes the bring-up failure where edges climbed steadily but frames stayed
    at 0 and no button ever decoded.
    The MFL wire lands on connector pin 7 and reaches GPIO39 through the MFSW
    board's aux light-sense resistive network, which is non-inverting -- unlike
    the bench rig (MFL-FINDINGS.md), whose 4N35 optocoupler inverts and which
    kSignalInverted was written for. With the flag set true the framing hunted
    for the >5ms inter-message idle gap on the LOW phase, where nothing ever
    exceeds ~0.5ms, so s_haveSync never armed and every pulse was discarded.
    Adds the phase measurement that established this. It times both levels off
    the raw pin state, be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
    [mfl.cpp]
2026-08-24 Ignore tool-generated .history/ snapshots
    KiCad drops local file-history snapshots next to the project, including a
    nested .git that would otherwise be committed as a gitlink.
2026-08-24 Add toolchain/version reference for cross-machine handover
    Documents exact PlatformIO/esptool/platform/framework/library versions
    this repo builds against, plus the main gotcha: every platformio.ini
    declares platform = espressif32 unpinned, which resolves to the pioarduino
    fork here rather than the official registry -- a likely cause of
    machine-specific build/flash failures if that fork was never installed.
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2026-08-24 Master: add Bench Mode override to keep ESP-NOW alive without CAN
    ignitionOn is derived purely from CAN bus activity (the dedicated
    ignition-sense GPIO was removed a while back and repurposed for the MFL
    signal), so powerIsBusy()'s espnowEnabled && ignitionOn check is always
    false on a bench with no CAN bus connected -- the 1-minute idle timeout
    then correctly (by its original in-vehicle design) drops the WiFi radio,
    which reads as a bug during bench testing but isn't one.
    Adds a persisted "Bench Mode" toggle (Settings -> Slave Display) that
    forces powerIsBusy() true unconditionally. Off by default -- the real
    install powers the master from switched 12V gated by ignition, so this
    condition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
    [app.js]
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
